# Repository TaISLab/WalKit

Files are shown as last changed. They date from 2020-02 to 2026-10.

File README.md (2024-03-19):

# WalKit


<p align="center">
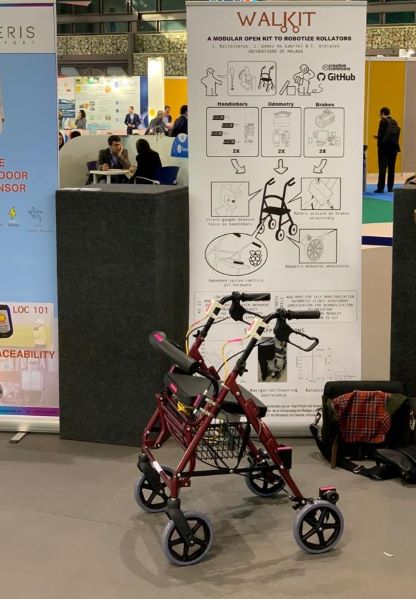
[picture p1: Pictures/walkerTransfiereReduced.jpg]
  
</p>

WalKit is an open hardware project created to monitor the elderly. It is modular, so different parameters, such as weight-bearing, cadence, activity duration, walking speed or other spatiotemporal gait parameters can be monitoring. 

- Packages in WalKit repository:
    - firmware: arduino codes for handles and wheels. 
    - hardware: 3d models and schematics.
    - walker_arduino: ros2 nodes to interact with USB arduino boards.   
    - walker_bringup: robot specific configuration scripts and tools. 
    - walker_centroid_support: obtains weight centroid based on current support.
    - walker_description: robot description.  
    - walker_diff_odom: odometry node.
    - walker_loads: reports partial supports on each leg.
    - walker_msgs: custom handle and wheel encoder msgs.
    - walker_navigation2: nav2 configuration for walker (TODO). 
    - walker_plot: Publishes Arrow marker based on handle force readings.  
    - walker_py_cluster: (TODO)
    - walker_simulation: roller simulation in gazebo.
    - walker_slam: (TODO)
    - walker_step_detector: reports step position.
    - walker_web_gui: web interface for tests.
            
- Repositories forked for this project
    - aws-robomaker-hospital-world: simulated hospital for gazebo.  
    - bwt901cl_pkg: IMU package.   
    - csm: ROS2 port of Andrea Censeis Scan matcher, needed by laser scan matcher package.
    - leap_motion: stereo camera package (DOES NOT WORK WITH arm64)  
    - ros2_laser_scan_matcher: provides odometry from laser readings.
    - rplidar_ros: RPLidar A1 package. 

<p align="right">(<a href="#top">back to top</a>)</p>

<!-- USAGE EXAMPLES -->
## Usage
The system can be launched with the following:
```
cd ~/walker_ws/src/WalKit/walker_bringup/config/
tmule -c walker.yaml launch --tag core
```
If you want to automatically start recording a rosbag as well, remove 'tag' option. They will be stored at '~/bagFolder'.

ROS launch files can be monitored at the tmux session. You can attach to it with the following command:
```
tmux a -t walker_ros2
```

You may have noticed we use Marc-Hanheide's [TMuLE](https://github.com/marc-hanheide/TMuLE) program to configure and manage a [tmux](https://github.com/tmux/tmux) session running all the components. TMuLE can be installed with:
```
sudo -H pip3 install tmule
```

<p align="right">(<a href="#top">back to top</a>)</p>

<!-- CONTRIBUTING -->
## Contributing

If you have a suggestion that would make this better, please fork the repo and create a pull request. You can also simply open an issue with the tag "enhancement".
Don't forget to give the project a star! Thanks again!

1. Fork the Project
2. Create your Feature Branch (`git checkout -b feature/AmazingFeature`)
3. Commit your Changes (`git commit -m 'Add some AmazingFeature'`)
4. Push to the Branch (`git push origin feature/AmazingFeature`)
5. Open a Pull Request

<p align="right">(<a href="#top">back to top</a>)</p>

<!-- LICENSE -->
## License

This project is licensed under the Creative Commons Attribution 4.0 - see [LICENSE](https://github.com/TaISLab/WalKit/blob/master/LICENSE) file for details.

<p align="right">(<a href="#top">back to top</a>)</p>

<!-- CONTACT -->
## Contact

Manuel Fernandez-Carmona - [@ermanazas](https://twitter.com/ermanazas) - manolofc at gmail.com

Project Link: [https://github.com/TaISLab/WalKit/tree/humble](https://github.com/TaISLab/WalKit/tree/humble)

<p align="right">(<a href="#top">back to top</a>)</p>

<!-- ACKNOWLEDGMENTS -->
## Acknowledgments

This work is funded by [Programa Proyectos RETOS del Ministerio de Ciencia, Innovación y Universidades (SAVIA: Sistema de Autonomía Variable para movIlidad Asistida, Ref: RTI2018-096701-B-C21)](http://www.grupoisis.uma.es/index.php?option=com_jresearch&view=project&task=show&id=208&Itemid=18&lang=es) at Málaga University, Spain

[Plan Propio de la Universidad de Málaga (E3-PROYECTOS DE PRUEBA DE CONCEPTO (E3/02/18))](https://www.uma.es/servicio-de-investigacion/cms/menu/plan-propio-de-investigacion/?set_language=en) at Málaga University, Spain

This great readme is based on [Othneil Drew](https://github.com/othneildrew/Best-README-Template)'s README template.

<p align="right">(<a href="#top">back to top</a>)</p>

<!-- MARKDOWN LINKS & IMAGES -->
<!-- https://www.markdownguide.org/basic-syntax/#reference-style-links -->
[contributors-shield]: https://img.shields.io/github/contributors/TaISLab/WalKit
[contributors-url]: https://github.com/TaISLab/WalKit/graphs/contributors
[forks-shield]: https://img.shields.io/github/forks/TaISLab/WalKit
[forks-url]: https://github.com/TaISLab/WalKit/network/members
[stars-shield]: https://img.shields.io/github/stars/TaISLab/WalKit
[stars-url]: https://github.com/TaISLab/WalKit/stargazers
[issues-shield]: https://img.shields.io/github/issues/TaISLab/WalKit
[issues-url]: https://github.com/TaISLab/WalKit/issues
[license-shield]: https://img.shields.io/github/license/TaISLab/WalKit
[license-url]: https://github.com/TaISLab/WalKit/blob/master/LICENSE
[product-screenshot]: images/screenshot.png

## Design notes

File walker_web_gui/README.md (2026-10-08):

# walker_web_gui

Web GUI to monitor the Walker and configure a test session, plus a console
tool to publish the same configuration. Static HTML/JS (no build step) that
talks to ROS 2 through rosbridge.

## Web GUI

rosbridge must be running:

    ros2 launch rosbridge_server rosbridge_websocket_launch.xml

Serve the page and open `http://<robot-ip>:4243/`:

    cd gui && python3 -m http.server 4243

Two tabs:
- **Monitor** (read-only): handle/leg loads, wheel encoders, IMU and a top-down
  view. Values with no recent data turn amber (stale) and then `—` (dead), so a
  frozen topic is not mistaken for a live one.
- **Sesión**: user data (id, gender, age, height, weight, Tinetti, condition)
  and handle height. **Actualizar configuración** publishes everything and is
  red while the form differs from what was last published.

Published topics: `/user_desc` (`walker_msgs/UserDesc`) and `/handle_height`
(`std_msgs/Int32`), both latched. Subscribed topics: loads, wheels, IMU, laser,
odom, and the two above.

The GUI does not start/stop the rosbag recording.

### rosbridge address

Defaults to `ws://<hostname used to open the page>:9090`. To override it, open
the page with `?ros=ws://<host>:9090` or use the gear icon next to the
connection status. The choice is remembered per browser (`localStorage`).
The connection is retried automatically with backoff.

### Layout

- `gui/index.html`: page structure.
- `gui/css/style.css`: styling.
- `gui/js/ros-link.js`: rosbridge connection with auto-reconnect, and the
  stale/dead tracking of displayed values.
- `gui/js/plot.js`: top-down Plotly view.
- `gui/js/app.js`: wires topics to the DOM and handles the configuration form.

## Console tool

Publishes the same `/user_desc` and `/handle_height` (transient_local) without
the GUI:

    ros2 run walker_web_gui console_config.py user_id:="manusete" gender:="Masculino" \
        age:="46" height:="175" weight:="104" tinetti_score:="28" \
        description:="Test ida y vuelta" handle_height:="4"

- Omitted fields take the GUI defaults (`UCAmI`, `Masculino`, 42, 175, 92, 24,
  `No previous condition`, handle height 4).
- `gender` is `Masculino` or `Femenino`, `tinetti_score` is 0-28, `handle_height`
  is 0-4.
- The node keeps running so late subscribers still get the latched values;
  Ctrl+C to exit. Add `once:="true"` to publish and exit instead.

Publishing from the console does not update the GUI form fields, and pressing
**Actualizar configuración** in the GUI overwrites what the console published.

## Licenses

Package: Creative Commons (see the repository `LICENSE`).

Bundled third-party libraries in `gui/`:
- roslibjs (`static.robotwebtools.org/`): BSD.
- plotly.js v1.58.5 (`cdn.plot.ly/`): MIT.

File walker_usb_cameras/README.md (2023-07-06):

# USB CAMERA CONFIGURATION PACKAGE

The aim of this package is to contain all calibration and configuration files needed to use an usb camera into walker system. 
This file is mostly a summary from info taken at:

[usb cam github](https://github.com/ros-drivers/usb_cam/tree/ros2)

[navigation tutorials: calibrating the camera](https://navigation.ros.org/tutorials/docs/camera_calibration.html)

[stereo calibration](http://wiki.ros.org/camera_calibration/Tutorials/StereoCalibration)

[ros2 stereo calibration](https://jeffzzq.medium.com/ros2-image-pipeline-tutorial-3b18903e7329)
## Check USB Camera
First step is check that camera works on our system.

### First terminal. 
Launch camera node without configuration:
```console
ros2 run usb_cam usb_cam_node_exe --ros-args -r __ns:=/camera
```

That command will show all possible formats, resolutions and fps and will start publishing data on ROS2.
```console
[INFO] [1688469843.164735462] [usb_cam]: Starting 'default_cam' (/dev/video0) at 640x480 via mmap (yuyv) at 30 FPS
[INFO] [1688469843.340893099] [usb_cam]: This devices supproted formats:
[INFO] [1688469843.340996505] [usb_cam]: 	YUYV 4:2:2: 640 x 480 (30 Hz)
[...]
[INFO] [1688469843.341301354] [usb_cam]: 	YUYV 4:2:2: 800 x 600 (20 Hz)
[...]
[INFO] [1688469843.341391412] [usb_cam]: 	YUYV 4:2:2: 1280 x 960 (5 Hz)
[...]
[INFO] [1688469843.341704075] [usb_cam]: 	Motion-JPEG: 800 x 600 (30 Hz)
[...]
[INFO] [1688469843.341899575] [usb_cam]: 	Motion-JPEG: 1280 x 960 (30 Hz)
[...]
[INFO] [1688469843.341927310] [usb_cam]: Setting 'brightness' to 50
[INFO] [1688469843.369696697] [usb_cam]: Setting 'white_balance_temperature_auto' to 1
[INFO] [1688469843.369725452] [usb_cam]: Setting 'exposure_auto' to 3
[INFO] [1688469843.378898988] [usb_cam]: Setting 'focus_auto' to 0
unknown control 'focus_auto'

[INFO] [1688469843.393069446] [usb_cam]: Timer triggering every 33 ms

```

Take note of the available formats, sizes and fps, as we will need them later on our "Params.yaml" file. 
Do not stop this command and open a second terminal.

### Second terminal. 
Here we will check that images are properly transmitted into ROS. First, lets check there are images:
```console
ros2 topic hz /camera/image_raw
```

We will see that FPS are similar to what was available.
```console
average rate: 29.813
	min: 0.032s max: 0.036s std dev: 0.00194s window: 31
average rate: 29.788
	min: 0.032s max: 0.036s std dev: 0.00195s window: 61
average rate: 29.819
	min: 0.032s max: 0.036s std dev: 0.00194s window: 91
```

Second command, see if the topic actually contains images:
```console
ros2 topic bw /camera/image_raw
```

We should see a decent amount of MB/s going around:
```console
Subscribed to [/camera/image_raw]
18.92 MB/s from 29 messages
	Message size mean: 0.61 MB min: 0.61 MB max: 0.61 MB
18.35 MB/s from 58 messages
	Message size mean: 0.61 MB min: 0.61 MB max: 0.61 MB
18.38 MB/s from 88 messages
	Message size mean: 0.61 MB min: 0.61 MB max: 0.61 MB
```

Finally, check that the topic can be seen in a ros2 app:
```console
ros2 run rqt_image_view rqt_image_view
```

Camera seems to work. Now we are ready to build both configuration and calibration files.

## configuration file (params.yaml)

This is the configuration file used by ROS2. It defines the camera configuration used. For example for our camera at video0 a params.yaml file:

````json
/**:
    ros__parameters:
      video_device: "/dev/video0"                                                   # <----------------- EDIT THIS TO MACH YOUR SYSTEM
      framerate: 20.0                                                               # <----------------- Taken from usb_cam_node_exe command
      io_method: "mmap"
      frame_id: "camera"                                                            # <----------------- careful with multiple cam systems
      pixel_format: "yuyv"                                                          # see usb_cam package, supported_formats for list of supported formats
      image_width: 800                                                              # <----------------- Taken from usb_cam_node_exe command
      image_height: 600                                                             # <----------------- Taken from usb_cam_node_exe command
      camera_info_url: "package://walker_usb_cameras/config/jpc_camera_info.yaml"   # <----------------- Calibration file. See next section
      camera_name: "jp_camera"                                                      # <----------------- This name must match whatever you put in the info_url file
      brightness: -1
      contrast: -1
      saturation: -1
      sharpness: -1
      gain: -1
      auto_white_balance: true
      white_balance: 4000
      autoexposure: true
      exposure: 100
      autofocus: false
      focus: -1
````

camera_info_url file will be created by callibration in next section.

## calibration file (camera_info.yaml) 

First we need a checkerboard for calibration. You can check [calib.io website](https://calib.io/pages/camera-calibration-pattern-generator) to generate any pattern. Specifically, we are using a “8x10” checkboard with 20mm squares. 

Actually we use a 7x9 checkerboard with 20mm squares, but calibration uses the interior vertex points, so a “8x10” board uses the interior vertex parameter “7x9”.

In a well-lit area, clear of obstructions and other check board patterns, point the checkboard to the camera and launch the camera calibration node:

```console
ros2 run camera_calibration cameracalibrator --size 7x9 --square 0.02 --ros-args -r image:=/camera/image_raw -p camera:=/my_camera
```

Now move, tilt and rotate the checkboard around until the calibrate button is highlighted. 

Click it to see the results. It takes around the minute for calibration to take place.

After the calibration is completed the save and commit buttons light up. And you can also see the result in terminal.

Press the save button to see the result. Data is saved to “/tmp/calibrationdata.tar.gz”

Inside the tar file, “ost.yaml” file is our camera_info.yaml, save from the "camera_name" field that needs to match the value in "params.yaml" file.

## launcher file
Last step is to create a launch file that uses our params.yaml to configure our camera. There is one at launch folder that can be used as template, just by changing the params.yaml file.

## STEREO USB Cameras

Create configuration file individually for each camera and create a launcher file with two 'usb_cam_node_exe' nodes, one per camera (see est_camera.launch.py as example).

Now proceed with calibration, but tell calibrator to use two cameras, i.e.
```console
ros2 run camera_calibration cameracalibrator --size 7x9 --square 0.02 --no-service-check  --approximate=0.3  --ros-args -p camera:=/est_camera  --remap /left:=/camera/left/image_raw   --remap /right:=/camera/right/image_raw

```

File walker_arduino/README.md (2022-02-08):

checking that the driver is running 
'''
screen /dev/right_wheel 115200
'''

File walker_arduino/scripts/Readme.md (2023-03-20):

# Check info from device connected as 'ttyUSB4'
```bash
udevadm info --attribute-walk --path=/sys/bus/usb-serial/devices/ttyUSB4
```
# Try rules written at '/etc/udev/rules.d' folder
```bash
udevadm control --reload-rules && udevadm trigger
```

# Virtual terminal to see output from new device
```bash
screen /dev/left_handle 115200
```
# Solve problem arduinos not appearing as ttyUSBx
Remove brtty

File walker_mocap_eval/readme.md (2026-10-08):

# walker_mocap_eval

Herramientas offline para recalcular, a partir de los rosbags etiquetados
con mocap (`soma13kp`/`datasets/labeled_bags`), los mismos parametros que
publican los nodos de `walker_loads` en marcha real -- y, en el futuro,
cualquier otro estudio que cruce mocap con datos del andador (postura,
centroide, estabilidad...).

No es un paquete ROS: como `walker_step_detector/scripts/*.py`, son
scripts de analisis que se ejecutan directamente con
`python3 scripts/xxx.py` tras sourcear `/opt/ros/jazzy/setup.bash` (hace
falta `rosbag2_py`/`rclpy` para deserializar los bags), y no forman parte
del build de colcon.

## Por que un paquete nuevo (y no meterlo en walker_loads o walker_step_detector)

- `walker_loads` es el paquete del nodo ROS en produccion
  (`gait_monitor_speed`, `partial_loads`); no es el sitio para tooling de
  analisis offline.
- `walker_step_detector/scripts/mocap_bag_io.py` ya hace algo parecido,
  pero esta acoplado a las necesidades del detector de pasos (frame
  "laser", solo tobillos/rodillas). Los estudios del plan (paso 3: postura,
  centroide, angulos de codo...) necesitan el resto de keypoints
  etiquetados (hombros, caderas, muñecas...), asi que se generalizo aqui en
  vez de forzar ese acoplamiento.

La calibracion mocap->base_footprint (`mocap_to_base_footprint.yaml`) SI se
reutiliza tal cual desde `walker_step_detector/config/` (fuente unica),
solo se referencia por ruta relativa por defecto.

## Estructura

```
mocap_eval/            <- libreria importable (sin dependencia de ROS salvo bag_io.py)
  bag_io.py             lectura de bags etiquetados, marcadores/rigid_bodies, proyeccion mocap->frame andador
  contact_events.py     eventos/intervalos de apoyo por pie a partir de cinematica del tobillo (mocap no mide carga)
  gait_metrics.py       puerto puro-Python de walker_loads/gait_monitor_speed.py (GaitMonitorSp)
  posture_metrics.py    inclinacion de tronco, ancho de paso, doble apoyo, margen de estabilidad lateral (punto 3)
  cog_estimation.py     centro de gravedad por modelo segmentario (De Leva 1996) + sexo/peso del usuario (punto 3)
  extra_metrics.py      codo, muñeca, reparto de peso en manetas, yaw/curvatura, oscilacion vertical del CoM, indice de
                        inestabilidad, Symmetry Index (puntos 3-elbow/4/5/8/9/11 del plan + punto 2 de la ampliacion)
  imu_metrics.py        RMS, Harmonic Ratio, regularidad por autocorrelacion, y aceleracion AP/ML del andador por mocap
                        (punto 1 de la ampliacion)
  correlation_utils.py  correlacion de Pearson por sujeto (CA/LA/MF/MT) + TOTAL (puntos 2 y 5 de la ampliacion)

scripts/   (orden de ejecucion y ejemplos de comandos: ver scripts/README.md)
  compute_gait_from_mocap.py       CLI: bag(s) etiquetado(s) -> Step/Stride time/length, NoS, d, CAD, WV (punto 1 del plan)
  selftest_gait_metrics.py         auto-test con datos sinteticos (sin bags), valida el puerto del algoritmo
  mocap_odom_bridge.py             nodo ROS: republica rigid_bodies[0] (mocap) como /odom (ver punto 2 mas abajo)
  compare_gait_mocap_vs_walker.py  punto 2: lanza el pipeline real (replay_offline.launch.py) contra cada bag,
                                    graba lo que publica gait_monitor_speed y lo compara con compute_gait_from_mocap.py
  compute_posture_from_mocap.py    CLI: bag(s) etiquetado(s) -> parametros posturales/estabilidad (punto 3)
  selftest_posture_metrics.py      auto-test con datos sinteticos (sin bags), valida la geometria de posture_metrics.py
  compute_cog_from_mocap.py        CLI: bag(s) etiquetado(s) -> centro de gravedad (modelo De Leva + sexo/peso, punto 3)
  selftest_cog_estimation.py       auto-test con datos sinteticos (sin bags), valida el modelo segmentario
  compare_cog_mocap_vs_walker.py   punto 3 (comparacion): CoM de mocap vs /support_centroid real (walker_centroid_support)
  eval_odom_against_mocap.py       evalua una odometria grabada (/odom del EKF laser+IMU, walker_bringup) contra el mocap:
                                    ATE tras alinear con Umeyama 2D + deriva en % del recorrido (antes en walker_step_detector/scripts)
```

## Uso

```bash
source /opt/ros/jazzy/setup.bash
cd WalKit/walker_mocap_eval

# validar la logica portada (no requiere bags ni $DATASETS)
python3 scripts/selftest_gait_metrics.py

# un bag
python3 scripts/compute_gait_from_mocap.py --bag $DATASETS/labeled_bags/CA_test01

# todos los bags etiquetados
python3 scripts/compute_gait_from_mocap.py --bags-dir $DATASETS/labeled_bags \
    --out /tmp/mocap_gait_results.json
```

## Recorte a la ventana `/tag` (punto 1 y 2, por defecto)

Cada bag de `datasets/labeled_bags` trae exactamente 2 mensajes en el topic
`/tag` (`builtin_interfaces/msg/Time`) -- los mismos marcadores de
inicio/fin de test (pulsacion de boton) que usa `mocap_analysis/scripts/
merge_rosbags.py` para sincronizar y recortar bags al fusionarlos. Fuera de
esa ventana suele haber tiempo de calibracion/colocacion del usuario, no
marcha real: en `CA_test01`, por ejemplo, la ventana `/tag` dura 52.9 s de
los 89.3 s totales del bag.

Por defecto (`compute_gait_from_mocap.py` y `compare_gait_mocap_vs_walker.py`,
`--ignore-tags` para desactivarlo en ambos):
  - **Lado mocap**: `/labeled_markers` y `/rigid_bodies` se recortan a
    `bag_io.read_tag_window()` antes de detectar eventos de apoyo.
  - **Lado andador** (punto 2): `replay_offline.launch.py` arranca el
    replay en el primer `/tag` (nuevo argumento `start_offset`, segundos de
    bag desde su propio inicio, `ros2 bag play --start-offset`) y
    `compare_gait_mocap_vs_walker.py` solo espera lo que dura la ventana
    entre los dos `/tag` (en vez de la duracion completa del bag), para que
    ambos lados vean la misma porcion "activa" del test.

Impacto en `CA_test01` (mocap-only, bag completo -> ventana `/tag`): cadencia
59.2 -> 85.0 pasos/min, velocidad 0.329 -> 0.542 m/s, NoS 87 -> 75 (menos
pasos porque la ventana es mas corta, pero mas *densos* -- el tiempo muerto
fuera de la ventana no aportaba pasos reales, solo alargaba `Tr` y diluia
la cadencia). Es una correccion sistematica: todo el reparto de tiempo real
de marcha estaba subestimando la velocidad/cadencia real del usuario al
promediar sobre tiempo que no era marcha.

## Diseño: como se recalcula cada parametro

| Parametro (GaitStamped/WalkStats) | Como se obtiene aqui | Fuente en el andador real |
|---|---|---|
| Step/Stride time y length por pierna | `gait_metrics.py`, puerto **literal** de `GaitMonitorSp.update_stats()`/`timer_callback()`: mismas formulas, mismo criterio de arranque (>2 eventos por pierna), mismas medias acumuladas (`nanmean` desde el inicio) | `walker_loads/gait_monitor_speed.py` |
| Evento de "apoyo" por pierna | `contact_events.detect_stance_events()`: minimo de velocidad horizontal del marcador de tobillo (`l_ankle`/`r_ankle`) por episodio bajo un umbral (0.25 m/s por defecto) | `StepStamped.load` pasando a >0 (celula de carga) |
| Posicion del evento | Se proyecta desde el frame "map" del mocap al frame del andador ("laser") con `rigid_bodies[0].pose` + la calibracion ICP existente + el offset fijo laser<-base_footprint (igual que `walker_step_detector/scripts/mocap_bag_io.py`) | `StepStamped.position`, ya en frame "laser"/"base_footprint" (deteccion laser) |
| Distancia recorrida (`d`) | Arclength del propio `rigid_bodies[0]` (andador) en el mocap, acumulada entre el primer y el ultimo evento de paso | **Ver discrepancia abajo** |
| `avg_step_speed_{left,right,all}` | Media de (longitud de paso / tiempo de paso), no publicada por el nodo real pero si mencionada en el docstring/spec original de `GaitMonitorSp` | No publicada actualmente por ningun topic |

**Resultados sobre los 47 bags, solo mocap, con recorte `/tag`**
(`/tmp/mocap_gait_tagged_full.json`): sin fallos en ningun bag. Cadencia
media 100.4 pasos/min (std 29.4), velocidad media 0.403 m/s (std 0.119) --
sensiblemente mas altas y mas representativas de la marcha real que las
que salian promediando sobre el bag completo (esas incluian el tiempo de
calibracion/colocacion, ver seccion anterior). `SpL`/`SdL` medios
0.14-0.31 m segun pierna/campo, consistentes entre bags del mismo sujeto.

## Bug corregido en el nodo real (encontrado antes del punto 2)

`walker_loads/gait_monitor_speed.py::GaitMonitorSp.getTravelledDist()`
**no usaba la distancia real acumulada**: `self.travelled` se calculaba
correctamente en `odom_callback()` (suma de desplazamientos consecutivos de
`/odom`), pero `timer_callback()` llamaba a `getTravelledDist()`, que
ignoraba `self.travelled` y devolvia una formula con una constante de
prueba hardcodeada (`test_time = 14.48`, pista de `8.0` m, resultado capado
a 8m). Es decir, `d`, `CAD` y `WV` del nodo real no reflejaban la distancia
ni la velocidad reales del test. **Corregido**: `timer_callback()` ahora usa
`self.travelled` directamente; `getTravelledDist()` se elimino.

## Punto 2: pipeline real vs mocap, resultados sobre los 47 bags

`compare_gait_mocap_vs_walker.py` lanza `walker_loads/launch/
replay_offline.launch.py` (box_filter -> km_detect_steps -> partial_loads ->
mocap_odom_bridge -> gait_monitor_speed) contra cada uno de los 47 bags de
`datasets/labeled_bags`, graba el ULTIMO mensaje de `/left_gait_stats`,
`/right_gait_stats` y `/global_gait_stats` (GaitStamped/WalkStats son
acumulados desde el arranque del nodo, asi que el ultimo mensaje ya refleja
todo el historial) y lo compara campo a campo con `compute_gait_from_mocap.py`.

**`/odom` real no es viable en estos bags**: `/left_wheel`/`/right_wheel`
(walker_diff_odom) estan rotos -- comprobado en CA_test01, `/right_wheel`
no tiene ni un mensaje y `/left_wheel` esta congelado (3475->3476 ticks en
~90s). `mocap_odom_bridge.py` republica `rigid_bodies[0]` (mocap) como
`/odom` en su lugar -- valido porque `self.travelled` solo acumula deltas
de posicion consecutivos, invariante a que frame se use.

Resultados **tras el fix de timestamp** (43/47 bags con datos suficientes;
ver tambien el docstring de `replay_offline.launch.py` para el detalle del
bug):

| Campo | MAE | MAPE | Lectura |
|---|---|---|---|
| `d` (distancia) | 0.17 m (mediana 2.3 cm) | 1.1% | **Validado**: coincide con mocap |
| `wv` (velocidad) | 0.044 m/s (mediana 0.034) | 15.7% | Bueno, hereda la calidad de `d` |
| `cad`/`NoS`/`SpT`/`SdT` | ver abajo | ver abajo | **Bimodal**: 13 bags muy bien, 30 todavia mal -- no es un error uniforme |

**Causa raiz encontrada y corregida** (no era un bug de `gait_monitor_speed`):
se descarto primero la hipotesis de zona de deteccion fija en tests de
"movimiento en circulos" (la mayoria de los 47) -- los tests "ida y vuelta"
(LA_test\*, sin ese patron) mostraban el mismo subconteo severo, y
`fixed_frame_active_area_x`/`_y` (que este launcher pasaba a
`km_detect_steps`) resultaron ser parametros **muertos** (el .cpp nunca los
lee, ya quitados del launcher).

La causa real estaba en `walker_step_detector/src/km_detect_steps.cpp`:
con `kalman_enabled: true` (necesario aqui -- con `false`,
`StepStamped.tracked` nunca se pone a `true` y `partial_loads` no publica
nada en absoluto), `laserCallback()` sellaba cada `StepStamped` predicho con
`this->now()` (reloj de pared) en vez del timestamp del propio escaner. En
vivo eso no importa (reloj de pared ~= tiempo del sensor), pero reproduciendo
un bag a `--rate 4.0` (el valor por defecto de este launcher) el reloj de
pared avanza 4 veces mas rapido que la linea de tiempo real del bag -- y
`Tr`/`SpT`/`SdT` (calculados como diferencias de esos timestamps) salian
truncados a ~1/rate de su valor real. Confirmado reproduciendo a
`rate:=1.0` con el bug todavia presente (Tr paso de ~12% a ~73% de la
duracion real del bag, sin tocar nada mas) antes de tocar el C++.
**Corregido**: se sella con `rclcpp::Time(scan->header.stamp)` en su lugar
(recompilado con `colcon build --packages-select walker_step_detector`).
Tras el fix, a `rate=4.0`, `Tr` en CA_test01/02/03 paso de ~10s a ~50-60s
(de ~85-90s reales), y `CA_test03` (antes sin datos) ya produce resultados.

Tras el fix, sobre los 47 bags, el resultado es **bimodal**, no un error
uniforme:

- **13 bags funcionan bien** (`MF_test17-20`, `MT_test11-20` salvo
  `MT_test13`): NoS del walker entre 70% y 153% del de mocap, `Tr` cubre
  todo el bag, errores de SpT/SdT por debajo de ~2s.
- **30 bags siguen mal** (todos los `CA_test*` y `LA_test*` restantes, y
  `MF_test01-15`): NoS del walker solo 8-23% del de mocap, igual de mal que
  antes del fix.
- **4 bags sin datos**: `CA_test03`, `LA_test5`, `MF_test02`, `MF_test16`.

Se comprobo si la diferencia esta en la calidad del propio `/scan` (huecos,
timestamps duplicados o no monotonos) entre un bag "bueno" y uno "malo":
**no lo esta** -- `CA_test01` (malo) y `MF_test17` (bueno) tienen el mismo
comportamiento de timestamp en `/scan` (mediana de intervalo ~0.12-0.18s,
sin duplicados, sin retrocesos), y `MF_test16` (misma sesion y calidad de
escaneo que `MF_test17`) sigue sin producir ningun dato. Es decir, lo que
diferencia un bag bueno de uno malo pasa DESPUES del `/scan` -- dentro del
clustering/tracking de `km_detect_steps` o de la asignacion de carga de
`partial_loads` -- y no se ha perseguido mas en esta sesion: hay una tarea
marcada para `walker_step_detector` sobre esto (el usuario ya la inicio
como sesion aparte mientras esta investigacion seguia en marcha aqui --
revisar ambas antes de seguir, y usar esta lista de bags buenos/malos como
punto de partida).

### Segunda causa encontrada (walker_step_detector): `ms_period` mal nombrado

La tarea marcada arriba ("hay una tarea marcada para walker_step_detector...
revisar ambas antes de seguir") ya tiene respuesta: la diferencia entre los
13 bags "buenos" y los 30 "malos" no estaba en `km_detect_steps` ni en
`/scan`, sino en `partial_loads.launch.py`. Ese launcher pasaba
`{'period': 0.05}` al nodo `partial_loads`, pero `partial_loads.cpp` nunca
declara un parametro `period` -- solo `ms_period` (int, ms, default 500).
El valor de 0.05 (pensado como 50ms/20Hz) se ignoraba en silencio y el nodo
corria siempre a su default de 2Hz.

Por que eso explica justo el patron **bimodal**: `partial_loads` decide
"que pierna carga" en un `create_wall_timer` -- reloj de PARED, no afectado
por `--rate` del bag. A 500ms de periodo real y `rate=4.0`, cada muestra de
esa decision cae cada ~2s de tiempo de BAG. Un bag con zancada lenta (SpT
mayor que esos ~2s) todavia captura suficientes cruces load>0 para verse
razonable; un bag con zancada mas rapida que el intervalo de muestreo
alias-a por completo la señal -- exactamente los 30 bags "malos" (y los 4
sin ningun dato, caso extremo de lo mismo).

**Fix**: `partial_loads.launch.py` ahora pasa `{'ms_period': 50}` (nombre
correcto). Sin recompilar (es un parametro de lanzamiento, no C++).
Revalidado con `compare_gait_mocap_vs_walker.py` sobre los 47 bags
completos (`ROS_DOMAIN_ID` propio, ver `ROS_DOMAIN_ID_EVAL` en el script):

| Campo | Antes (tras fix de timestamp, arriba) | Despues (+ fix de `ms_period`) |
|---|---|---|
| Bags con datos suficientes | 43/47 (4 sin ningun `GaitStamped`) | **47/47** |
| `NoS` | bimodal (13 bien, 30 al 8-23% del real) | MAE=23.5 pasos, medianaAE=18, MAPE=25.1% (uniforme, sin bags a cero) |
| `d` | MAPE 1.1% | MAPE 1.3% (sin cambio, esperado) |
| `wv` | MAPE 15.7% | MAPE 13.2% |
| `cad` | — | MAE=22.5, MAPE=29.4% |
| `SpT`/`SdT`/`SpL`/`SdL` | heredaban el error bimodal de NoS | siguen con MAPE 30-230% -- heredan el ~25% de error de `NoS` que queda |

`NoS` pasa de infracontar severamente (o fallar del todo) a un error
uniforme del ~25%, sin bags catastroficos. Ese ~25% residual es,
presumiblemente, ruido de `km_detect_steps` (fuerza siempre exactamente 2
clusters por k-means sobre `/scan_feet`, sin filtro de confianza como el
Random Forest de `detect_steps` -- ver `getCentroids()`): con la señal ya
muestreada a un ritmo razonable, ese ruido dispara algun cruce `load>0` de
mas o de menos. Detalle y numeros del spot-check inicial (2 bags) en el
comentario de `partial_loads.launch.py`. No se ha perseguido mas aqui --
encaja con el trabajo ya activo en `walker_step_detector` sobre la calidad
de deteccion de `km_detect_steps` frente a `detect_steps` (RF).

**Reejecutado sobre los 47 bags completos** para este informe (mismo
`compare_gait_mocap_vs_walker.py`, `ROS_DOMAIN_ID` propio): **47/47 bags con
datos**, ningun fallo. `NoS` MAE=31.4 pasos, medianaAE=31, MAPE=34.6% --
algo peor que el 25.1% del spot-check anterior, esperable dado que el
muestreo de `partial_loads` sigue en reloj de pared (`create_wall_timer`,
no en tiempo de bag) y por tanto tiene algo de varianza de una corrida a
otra. `d` (MAPE 1.3%) y `wv` (MAPE 13.4%) se mantienen validados.

Encontrado en esta corrida: `CA_test09` tiene valores de `SpL`/`SdL` del
andador disparatados (`left_sdl`=87m, `right_spl`=39m, `right_sdl`=76m de
"longitud de zancada") que inflan artificialmente el MAPE agregado de esos
4 campos (200-2800%) muy por encima de lo que reflejan el resto de bags
(medianaAE de esos mismos campos: 0.15-0.21 m, mucho mas razonable -- usar
la mediana, no la media, al leer esa fila de la tabla).

**Causa real de `CA_test09` y estado final, tras coordinarse con el hilo
`walker_step_detector` (mejoras)**: mi hipotesis inicial (clustering sin
filtro de confianza en `km_detect_steps`) no era la causa -- esa sesion
diagnostico el verdadero origen: `TrackLeg::t` se inicializaba a 0 como
centinela de "nunca predicho", pero `predict_step()` lo usaba tal cual en
el primer `u.dt()=(ti-t)*1e-9`, dando un dt de ~1.79e9s (segundos desde el
epoch Unix) en vez de un intervalo real. Ese dt gigante dispara la
covarianza del EKF desde el primer ciclo (via el jacobiano de
`SystemModelLeg.hpp`), y la siguiente actualizacion salta a cientos de
metros -- afecta por igual a las tres variantes de detector (`km`, `rf`,
`seg`, mismo `TrackLeg` compartido); `rf`/`seg` no lo mostraban en
`CA_test09` por pura suerte de timing, no porque no les afecte. Fix (su
sesion, `track_leg.cpp::predict_step()`): si `t==0`, fijar `t=ti` antes de
calcular `dt` -- la primera prediccion usa `dt=0` en vez de "tiempo desde
el epoch".

De paso, esa sesion recomendo cambiar de `km_detect_steps` a `detect_steps`
(Random Forest) en `replay_offline.launch.py` -- validado por ellos en
95.7-95.9% de match_rate sobre estos mismos 47 bags (vs ~81% de `km`).
Aplicado, y de camino encontramos (yo) que `detect_steps.cpp` y
`detect_steps_s.cpp` tenian el MISMO bug de timestamp de reloj de pared que
ya habia corregido en `km_detect_steps.cpp` (`this->now()` en vez de
`scan->header.stamp`/`seg_array->header.stamp`) -- corregido en los tres.

**Resultado final, los tres fixes juntos (timestamp x3 variantes + `t==0`
del EKF + cambio a RF), sobre los 47 bags completos**:

| Campo | Solo timestamp+`ms_period` (arriba) | + `t==0` fix + RF (final) |
|---|---|---|
| Bags con datos | 47/47 | 47/47 |
| `NoS` | MAE=31.4, MAPE=34.6% | **MAE=24.6, medianaAE=20, MAPE=24.0%** |
| `d` | MAPE 1.3% | MAPE 1.3% (sin cambio, esperado) |
| `wv` | MAPE 13.4% | MAPE 15.4% |
| `cad` | MAPE 40.1% | MAPE 27.7% |
| `SpT`/`SdT` | MAPE 28-137% | MAPE 26-58% |
| `SpL`/`SdL` | MAPE 200-2800% (outlier `CA_test09`) | **MAPE 52-98%, sin outliers** |

`CA_test09` ya no tiene valores disparatados (antes 87/39/76 m de "longitud
de zancada", ahora 0.07-0.13 m como el resto de bags). El error residual de
`SpL`/`SdL`/`SpT`/`SdT` (25-100% MAPE) es ahora ruido "normal" de deteccion,
no un unico frame corrupto contaminando toda la media -- consistente con
que `gait_monitor_speed.py` sigue promediando con `nanmean` simple sin
rechazar outliers puntuales (no corregido, y ya no hace tanta falta con el
EKF corregido, pero sigue siendo una fragilidad de diseño a tener en cuenta
si aparece otro bug de esta familia).

### Rehecho con recorte a la ventana `/tag` (puntos 1 y 2)

Con el recorte a `/tag` activado por defecto (ver seccion arriba) en ambos
lados de la comparacion, sobre los 47 bags completos:

| Campo | Bag completo (estado anterior) | Ventana `/tag` (final) |
|---|---|---|
| `NoS` | MAE=24.6, MAPE=24.0% | MAE=22.9, medianaAE=16, MAPE=25.6% (similar) |
| `d` | MAPE 1.3% | MAPE 3.5% (peor, ver nota abajo) |
| `wv` | MAPE 15.4% | **MAPE 5.9%** (mejor) |
| `cad` | MAPE 27.7% | **MAPE 23.4%** (mejor) |
| `SpT`/`SdT` | MAPE 26-58% | MAPE 24-76% (similar, `right_spt` peor en algun bag puntual) |
| `SpL`/`SdL` | MAPE 52-98% | MAPE 49-87% (similar) |

`wv`/`cad` mejoran claramente (igual que ya se vio en mocap-only: promediar
sobre la ventana activa da una cadencia/velocidad mas representativa que
diluirla con tiempo de calibracion). `d` empeora un poco -- hipotesis mas
probable: con una ventana mas corta, el tiempo de arranque del pipeline real
(`partial_loads` necesita ver las 4 fuentes frescas antes de publicar nada,
`first_data_ready_`) es una fraccion mayor del total, así que se pierde
proporcionalmente mas distancia real al principio de la ventana que con el
bag completo. No investigado mas a fondo. El resto de campos se mantiene en
el mismo orden de magnitud que sin recortar -- el recorte a `/tag` no
"arregla" nada adicional sobre el punto 2 en si (esa mejora ya vino de los
fixes del hilo walker_step_detector), pero da una medida mas representativa
de la marcha real del usuario en ambos metodos, que es lo que se pidio.

## Punto 3: parametros posturales/de estabilidad desde mocap

`posture_metrics.py` (+ CLI `compute_posture_from_mocap.py`) implementa los
4 candidatos "baratos" de la tabla del plan (los que no requieren datos del
andador para calcularse, solo mocap) sobre la misma base que el punto 1
(`bag_io.py`, `contact_events.py`):

| Parametro | Como se calcula | Candidato a correlar con (andador) |
|---|---|---|
| Inclinacion de tronco (total, sagital, frontal) | Angulo entre el vector cadera_media->hombro_medio y la vertical, en cada frame donde esten los 4 marcadores (`l/r_shoulder`, `l/r_hip`) | Reparto de carga manetas/pies (`partial_loads`), centroide de soporte (`walker_centroid_support`) |
| Ancho de paso | Distancia lateral (proyectada al eje del andador via `rigid_bodies[0]` yaw) entre cada evento de apoyo y el del pie contrario mas cercano en tiempo -- reutiliza `contact_events.detect_stance_events()` del punto 1 | No publicado hoy; derivable de las mismas posiciones que ya usa el detector de pasos |
| Tiempo de doble apoyo (%) | Solape entre `contact_events.detect_stance_intervals()` de ambos pies, sobre el total | `is_left_load`/`is_right_load` de `gait_monitor_speed.py` ya existen internamente, no se publican |
| Margen de estabilidad lateral | Punto medio de caderas (proxy de CoM) proyectado sobre el eje lateral del andador, normalizado entre los DOS TOBILLOS reales (0=borde, 1=centro) -- misma formula que `walker_stability.py::y_sta`, pero con BoS real en vez de estimado por tablas antropometricas | **Validacion directa** de `StabilityStamped.sta` |

`indexed_nearest()` en `bag_io.py`: la primera version de `trunk_lean_series()`
usaba `nearest()` (escaneo lineal) contra 3 tracks por cada muestra de otro
(miles a ~120Hz) -- O(n^2), minutos por bag. Sustituido por una version
indexada con `bisect` (una vez por track, O(log n) por consulta): segundos
por bag. Cualquier funcion futura que consulte un track repetidamente
deberia usar `indexed_nearest()`, no `nearest()`.

Resultados con recorte `/tag` (por defecto ahora, `--ignore-tags` para el
bag completo): `/tmp/mocap_posture_tagged_full.json`, sin fallos en los 47
bags. El recorte cambia mucho una metrica en concreto: **doble apoyo**, que
con el bag completo salia 6-67% (dominado por el tiempo de pie quieto antes
y despues del test, que es doble apoyo permanente pero no marcha), baja a
un rango mucho mas realista de **3-56%** una vez restringido a la ventana
activa -- p.ej. `CA_test01` 44.8% -> 11.6%, `CA_test02` 56.8% -> 9.9%. El
resto de parametros cambia menos: inclinacion de tronco 3.9-35.7 (similar
rango, algo mas alta en general al quitar los tramos de pie quieto/recto),
ancho de paso 0.08-0.42 m, margen lateral 0.26-0.85.

**Correlacion "maneta baja -> mas inclinacion" mas clara con el recorte**:
CA (postura inclinada, `handle_height=0`, test07/08) 24.2 grados de media
vs 11.7 en el resto de tests del mismo sujeto (antes del recorte: 15.2 vs
11.3 -- la separacion se hace mucho mas nitida al quitar el ruido de los
tramos sin marcha real); MT (test19/20) 14.6 vs 9.8 (antes 13.4 vs 9.0).
Es exactamente el tipo de correlacion mocap<->parametro-del-andador (aqui,
`handle_height`) que busca el punto 3 del plan, y ahora con menos
solapamiento que antes de recortar a `/tag`.

Cruzar el resto de estos parametros con datos PUBLICADOS por el andador
(inclinacion de tronco vs asimetria real de `/left_handle`-`/right_handle`,
o el margen de estabilidad de aqui contra `StabilityStamped.sta`) es el
paso siguiente logico -- requiere decidir que bags tienen datos de
manetas/centroide utilizables (ver limitaciones del punto 2 arriba: la
extraccion en vivo depende del mismo pipeline con el problema de
`km_detect_steps` ya descrito) y no se ha hecho todavia.

## Punto 3: centro de gravedad (De Leva) vs `support_centroid` del andador

`cog_estimation.py` estima el CoM de cuerpo completo por frame combinando
la postura del mocap con el sexo y el peso del usuario (de
`test_config.txt`), usando el modelo antropometrico segmentario de
**De Leva (1996)** ("Adjustments to Zatsiorsky-Seluyanov's segment inertia
parameters", J Biomech 29(9):1223-30 -- tabla verificada contra el paper
original, no de memoria): cada segmento (tronco, brazo, antebrazo, muslo,
pantorrilla) se calcula interpolando entre sus dos articulaciones segun la
fraccion de posicion de De Leva; los 3 segmentos sin marcador propio en el
esquema de 13 keypoints (cabeza, manos, pies -- sin vertice/dedos/punta de
pie) se aproximan con su masa concentrada en la articulacion proximal
disponible (hombro, muñeca, tobillo). Esos 3 segmentos suman ~8.5% de la
masa corporal, y el sesgo que introduce esa aproximacion es casi todo
vertical (con el tronco razonablemente recto, cabeza/manos/pies caen casi
encima de su articulacion proximal en el plano horizontal) -- para
comparar la posicion horizontal contra `support_centroid` (el uso
previsto), el efecto es minimo. La ALTURA del usuario no se usa para
derivar la posicion (los segmentos ya tienen longitud real, medida por el
mocap en cada frame) -- solo como contraste (`com_height_frac_of_stature`).

**Resultados mocap-only sobre los 47 bags, con recorte `/tag`**
(`compute_cog_from_mocap.py`, `/tmp/mocap_cog_tagged_full.json`): sin
fallos en ningun bag. Fraccion CoM/estatura entre 0.552 y 0.608 (media
~0.59) -- practicamente identica al calculo sobre el bag completo (0.552-
0.613): a diferencia del doble apoyo (arriba), la altura del CoM no se ve
afectada por el tiempo de pie quieto (la postura en reposo es similar en
altura a la postura de marcha). Consistente con el valor tipico de
literatura para un adulto de pie (~0.55) -- algo mas alto, razonable dado
que el usuario sujeta las manetas del andador con los brazos levantados en
vez de colgando a los lados. Patron por sujeto: MT (67 kg) sistematicamente
mas bajo (0.552-0.578) que CA/LA/MF (0.571-0.608) -- para interpretar esto
como algo mas que variacion individual de proporciones corporales hace
falta cruzarlo con la altura real de manetas usada en cada test
(`handle_height` de `test_config.txt`), no hecho todavia.

**Comparacion contra el andador**: `compare_cog_mocap_vs_walker.py` anade
`walker_centroid_support` (topics por defecto, sin remapear: ya coinciden
con lo que publica `partial_loads`) a `replay_offline.launch.py`, graba
`/support_centroid` durante el replay real, y lo compara (media sobre toda
la grabacion, en frame "laser", proyectando el CoM de mocap con la misma
calibracion ICP que el punto 1/2 -- comparar medias en vez de instante a
instante porque `support_centroid` hereda el ruido de deteccion de piernas
que le queda a `km_detect_steps`).

**Resultado sobre los 47 bags: error medio ~15 cm entre el CoM de mocap
(De Leva) y el centroide de carga real del andador** -- mediana 0.155 m,
media 0.145 m excluyendo el bag con outlier (ver abajo), rango 3.6-29 cm en
el resto. Es una correlacion solida para una primera comparacion: dos
metodos completamente independientes (postura+antropometria vs celdas de
carga) situan el punto de equilibrio del usuario en el mismo sitio con
~15 cm de margen, sobre un andador cuya base mide del orden de 1 m.

`x` de ambos metodos es consistentemente negativo (-0.4 a -0.85 m mocap,
-0.5 a -0.79 m andador) y del mismo orden en todos los bags -- el usuario
carga tipicamente por detras del origen del frame "laser" en ambos metodos,
como cabria esperar. `y` de ambos ronda 0 en la mayoria de bags (usuario
centrado lateralmente), con las mismas excepciones logicas (MF_test17/18,
CA_test06: asimetria real, mayor en el metodo de mocap que en el del
andador -- consistente con que `support_centroid` reparte peso segun carga
MEDIDA en los 4 puntos de contacto, mientras que el CoM de mocap refleja la
postura completa, que puede desviarse mas).

**`CA_test09` sale como outlier severo** (`walker_y`=35.7 m, `dist_err_m`
=35.8 m): la MISMA deteccion espuria de `km_detect_steps` que ya contamino
`SpL`/`SdL` de `gait_monitor_speed` en este bag (punto 2 arriba) contamina
tambien `support_centroid` -- confirma que es un problema sistemico de
"sin filtro de confianza + promediado no robusto" que afecta a CUALQUIER
nodo que promedie sobre toda la sesion (`gait_monitor_speed` Y
`centroid_support`, ambos), no algo especifico de uno de los dos.

### Rehecho con el fix del EKF (`t==0`) + recorte a `/tag`

Repetido tras los fixes del punto 2 (RF + `t==0` del EKF) y con el recorte
a la ventana `/tag` activado por defecto en ambos lados: **error medio
0.107 m, mediana 0.106 m, maximo 0.199 m -- sin ningun outlier en los 47
bags** (antes: mediana 0.155 m con `CA_test09` disparado a 35.8 m). Mejora
en las tres cosas a la vez: el fix del EKF quita el outlier de raiz (igual
que en el punto 2), y el recorte a `/tag` quita el tiempo de pie quieto
(que desplaza el centroide real hacia una postura de reposo distinta de la
postura de marcha que describe el CoM de mocap). El patron de `x`/`y` por
sujeto/bag se mantiene igual que antes (ver parrafo anterior).

## Informe completo y flujo de ejecucion

`scripts/README.md` documenta el orden de ejecucion de todos los scripts
(metricas mocap -> `export_bag_timeseries.py` -> `derive_comparison_metrics.py`
-> `build_master_report_data.py` -> `generate_latex_report.py`). El informe
LaTeX resultante (11 puntos + ampliacion, tablas por bag con agregados POR
SUJETO CA/LA/MF/MT mas una fila TOTAL, formulas, bibliografia) se genera
con `generate_latex_report.py`; no se versiona el .tex/.pdf, se regenera.

Convencion de agregacion: cada bag es una repeticion de test de uno de 4
sujetos (prefijo `CA`/`LA`/`MF`/`MT`; 10/7/20/10 bags). Los agregados se
dan por sujeto, no mezclando los 47 bags, porque difieren en sexo, peso y
altura.

**Repetibilidad del replay (limitación abierta).** La reproducción del lado
andador no es determinista: a rate 4, `partial_loads` decide qué pierna
carga con un temporizador de reloj de pared, y el resultado depende de
dónde cae cada decisión en el bag (y de la carga de CPU). Dos ejecuciones
dieron MAPE del SpT izquierdo de 38% (30 sep-1 oct 2026) y 58% (6 oct 2026).
Todas las cifras del lado andador del informe son de **una sola ejecución,
la de octubre de 2026**, y las cifras escritas a mano en el texto de
`generate_latex_report.py` (literatura, limitaciones, conclusiones) hay que
revisarlas si se repite el replay; las tablas sí se recalculan. No está
cuantificada la variabilidad entre repeticiones. Lo calculado solo desde
mocap o sensores grabados (marcha mocap, postura, IMU, simetría) sí es
reproducible.

## Ampliacion: parametros nuevos con los sensores actuales del andador

Candidatos de la literatura que usan sensores que el andador YA lleva y
cuya precision se puede corroborar con mocap. Se comprobo contra los
topics realmente grabados en los bags (no solo contra el codigo): cada bag
trae `/bwt901cl/imu` + `/imu_filtered` (IMU WitMotion, en produccion solo
alimenta la velocidad angular del EKF) y los ticks crudos
`/left_wheel`/`/right_wheel`.

| # | Parametro | Sensor real | Referencia mocap | Modulo / script |
|---|---|---|---|---|
| 1 | RMS, Harmonic Ratio (Moe-Nilssen 1998), regularidad de paso/zancada Ad1/Ad2 (Moe-Nilssen & Helbostad 2004) | IMU del chasis (`/bwt901cl/imu_filtered`) | 2a derivada de `rigid_bodies[0]` | `imu_metrics.py`, `compute_imu_stability_metrics.py` |
| 2 | Symmetry Index (Robinson 1987) de fuerza en manetas vs asimetria cinematica de paso | `/left_handle`, `/right_handle` calibrados | SpT/SdT/SpL/SdL izq-dcha de `compute_gait_from_mocap.py` | `extra_metrics.symmetry_index`, `compute_handle_symmetry_vs_gait.py` |
| 5 | Correlacion inclinacion sagital de tronco vs margen de estabilidad lateral | (ninguno nuevo) | dos parametros ya calculados | `compute_lean_vs_margin_correlation.py` |
| 3 | Validacion de `walker_stability.py` (`/user_stability`) vs margen mocap | -- | -- | **bloqueado**, ver abajo |

(El candidato 4, auditar los encoders de rueda crudos, se descarto por
decision del usuario.)

**Se aprendio por el camino (bugs propios, ya corregidos):**
- Derivar mocap dos veces sobre sus timestamps reales NO funciona: el dt
  de `rigid_bodies` es irregular (mediana ~8.3 ms, pero con valores desde
  ~0.06 ms hasta ~80 ms), y dividir por ese dt casi nulo daba RMS de ~60
  m/s2 frente a ~0.5 del IMU. Solucion en `imu_metrics.walker_accel_ap_ml`:
  remuestrear a rejilla uniforme (60 Hz) -> media movil -> 2a derivada
  centrada de 3 puntos con dt constante.
- El Symmetry Index por muestra es inestable: la calibracion de maneta
  extrapola y da kg ligeramente negativos cerca de carga nula, con lo que
  el SI sale negativo o enorme. Para el escalar por bag se calcula el SI
  sobre la fuerza MEDIA de cada lado; para la serie por muestra
  (`handle_force_symmetry_series`) se recorta a kg>=0 y el SI es NaN si
  L+R < 0.5 kg.
- `autocorr_regularity` usa normalizacion sesgada (N en el denominador,
  N-lag en el numerador): para una señal perfectamente periodica el maximo
  teorico es (N-lag)/N < 1, no exactamente 1.

**Resultados (47 bags; IMU: 46/47, `MT_test11` sin muestras de IMU en la
ventana `/tag`):**
- IMU vs mocap: RMS_AP del mismo orden en ambas fuentes (tipicamente
  0.2-0.6 m/s2); HR y Ad1/Ad2 de la misma escala pero con mucha dispersion
  bag a bag. Excepcion conocida: `MF_test06` (RMS_AP mocap 3.2 vs IMU 0.4),
  un salto de tracking mocap que sobrevive al suavizado. El IMU esta en el
  chasis del andador, no en el tronco del usuario: los valores absolutos no
  son comparables con normas de la literatura (que usan tronco). El eje V
  del IMU incluye la gravedad (~9.8 m/s2); solo se compara AP/ML (el
  chasis apenas se mueve en z, no hay V fiable en mocap).
- Simetria por maneta: SI de maneta ~190% en el sujeto CA (carga muy
  asimetrica), 1-60% en el resto. Correlacion con la asimetria cinematica
  debil (|r| < 0.62 por sujeto, |r| < 0.16 en TOTAL): son manifestaciones
  parcialmente independientes de la asimetria; resultado honesto, no un
  fallo del metodo.
- Inclinacion vs margen lateral: r = -0.475 (CA), -0.298 (LA), -0.240
  (MF), +0.002 (MT), TOTAL -0.033. Ojo: la literatura (andadores
  instrumentados) habla del margen ANTERO-POSTERIOR, no del lateral que
  calcula `posture_metrics`; es una prueba indirecta de la hipotesis.

### Punto 3 bloqueado: `walker_stability.py`

Dos bloqueos, verificados contra el codigo y contra el contenido de los bags:
1. **Bug de aridad**: `centroid_callback()` llamaba a `get_bos_x()` con 5
   argumentos y el metodo acepta 4 (`TypeError` en cada mensaje de
   centroide). Corregido quitando el argumento sobrante `self.handle_x`
   (`handle_z` es la altura de maneta que espera `handlebar_height_m`).
2. **Frames TF ausentes**: el nodo hace `lookup_transform(base_footprint,
   left_handle_id / right_handle_id)`, y `/tf_static` de los bags solo trae
   `base_link`, `laser`, `wheel_left/right`, `witmotion`, `camera_*`. Con
   estos datos el nodo no puede calcular nada ni arreglado el bug 1. No se
   invento ningun TF para forzarlo: habria metido supuestos no verificables
   sobre la geometria de las manetas. Necesita que el robot real emita esos
   frames al grabar. Trabajo posterior de `walker_stability` va en un hilo
   aparte.

### CSV de las series nuevas

`python3 scripts/export_bag_timeseries.py --bags-dir $DATASETS --out-dir DIR --ampliacion-only`
(sin replay, solo lectura de bag; tambien se generan en la ejecucion normal).
Mismo eje `t_s` (segundos desde el primer `/tag`) que el resto de CSV:

| CSV | Columnas | Notas |
|---|---|---|
| `{bag}_imu_real_accel.csv` | `t_s, ap_m_s2, ml_m_s2, v_m_s2` | crudo, sin remuestrear; asume x=AP, y=ML, z=V (montaje no verificado fisicamente); incluye gravedad |
| `{bag}_mocap_walker_accel.csv` | `t_s, ap_m_s2, ml_m_s2` | rejilla uniforme 60 Hz |
| `{bag}_mocap_handle_symmetry.csv` | `t_s, left_kg, right_kg, si_pct` | kg>=0; `si_pct`=NaN si L+R<0.5 kg |

### Autotests nuevos

`scripts/selftest_imu_metrics.py` (RMS, HR, autocorrelacion, aceleracion
AP/ML sintetica) y `scripts/selftest_correlation_utils.py`.

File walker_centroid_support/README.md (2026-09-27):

# walker_centroid_support

Estima el centro de gravedad (centroide de apoyo) del usuario sobre el
andador, siguiendo el método de J. Ballesteros (IROS 2018), combinando la
carga soportada en cada pierna y en cada maneta con la posición de esos
cuatro puntos de apoyo.

Este paquete no mide nada por sí mismo: consume las salidas ya calibradas
de [`walker_loads`](../walker_loads) (carga en kg por pierna y por maneta)
y las posiciones/TFs que publican `walker_step_detector` y
`walker_description`. Es, esencialmente, una media ponderada por peso de
cuatro posiciones.

## Cómo funciona

En cada punto de apoyo hay una carga (kg) y una posición (m, en el frame de
los pies, normalmente `base_link`):

| Punto de apoyo | Carga | Posición |
|---|---|---|
| Pie derecho | `right_leg_load` (de `/right_loads`) | `position` del propio mensaje `StepStamped` |
| Pie izquierdo | `left_leg_load` (de `/left_loads`) | `position` del propio mensaje `StepStamped` |
| Maneta derecha  | `right_handle_weight` (de `/right_hand_loads`) | TF `right_handle` → frame de los pies (ver abajo) |
| Maneta izquierda| `left_handle_weight` (de `/left_hand_loads`) | TF `left_handle` → frame de los pies (ver abajo)  |

El centroide publicado es la media ponderada de esas 4 posiciones:

```
centroide = (right_leg_load  * pos(pie_derecho)   +
             left_leg_load   * pos(pie_izquierdo) +
             right_hand_load * pos(maneta_derecha) +
             left_hand_load  * pos(maneta_izquierda)) / carga_total
```

donde `carga_total` es la suma de las cuatro cargas medidas (no el peso
declarado del usuario, ver [Decisiones de diseño](#decisiones-de-diseño)).

### Posición de las manetas

Las manetas no publican su propia posición, solo su carga. La posición se
obtiene con una consulta TF (`tf2`) entre el frame de la maneta
(`header.frame_id` del mensaje de `/left_hand_loads` / `/right_hand_loads`,
p. ej. `left_handle_id`) y el frame en el que vienen los pies (el
`header.frame_id` del propio mensaje de step, normalmente `base_link`).
Esa consulta se repite en **cada ciclo del timer**, sin cachear el
resultado, para reflejar siempre la altura de maneta actual (ver
[Decisiones de diseño](#decisiones-de-diseño)).

### Ciclo de publicación

Un timer (`period`, 20 Hz por defecto) evalúa si hay datos nuevos desde el
último ciclo (`new_data_available`, marcado por cualquiera de las 4
suscripciones de carga). Antes de publicar nada:

1. Espera a haber recibido al menos un mensaje de cada una de las 4 fuentes
   de carga (`first_data_ready`).
2. Resuelve la TF de ambas manetas; si alguna falla (aún no hay TF, o el
   frame no existe), se salta ese ciclo y se reintenta en el siguiente.
3. Si la carga total medida es ≤ 0 (todavía no hay carga real, p.ej. nada
   más arrancar), también se salta el ciclo.

Cuando las tres condiciones se cumplen, publica un `geometry_msgs/PointStamped`
con el `header` del mensaje de step derecho (mismo frame que los pies).

## Topics

### Suscritos

| Topic (parámetro) | Tipo | Publicado por |
|---|---|---|
| `/left_hand_loads` (`left_hand_loads_topic_name`)  | `walker_msgs/msg/ForceStamped` | `walker_loads` (`partial_loads`) |
| `/right_hand_loads` (`right_hand_loads_topic_name`)| `walker_msgs/msg/ForceStamped` | `walker_loads` (`partial_loads`) |
| `/left_loads` (`left_loads_topic_name`) | `walker_msgs/msg/StepStamped`  | `walker_loads` (`partial_loads`) |
| `/right_loads` (`right_loads_topic_name`) | `walker_msgs/msg/StepStamped`  | `walker_loads` (`partial_loads`) |

`ForceStamped.force` en `/left_hand_loads` y `/right_hand_loads` ya viene
calibrado en kg (no es la lectura cruda del sensor); `StepStamped.load` en
`/left_loads`/`/right_loads` ya viene repartido entre piernas según la
lógica de `partial_loads` (Kalman de diferencia de velocidad + reparto
suave). Este nodo no vuelve a calibrar ni a repartir nada, solo pondera y
combina.

Además usa `tf2` (vía `tf2_ros.Buffer`/`TransformListener`) para resolver
la posición de las manetas; no hay un parámetro de topic para esto, es la
infraestructura TF estándar (necesita que `walker_description`'s
`handle_tf_publisher` esté publicando la TF `<frame de los pies> ->
{left,right}_handle_id`).

### Publicados

| Topic (parámetro) | Tipo |
|---|---|
| `/support_centroid` (`centroid_topic_name`) | `geometry_msgs/msg/PointStamped` |

## Parámetros

| Parámetro | Por defecto | Descripción |
|---|---|---|
| `left_hand_loads_topic_name` | `/left_hand_loads`  | Carga (kg) de la maneta izquierda, ya calibrada |
| `right_hand_loads_topic_name`  | `/right_hand_loads` | Carga (kg) de la maneta derecha, ya calibrada |
| `left_loads_topic_name` | `/left_loads` | Posición + carga (kg) del pie izquierdo |
| `right_loads_topic_name` | `/right_loads` | Posición + carga (kg) del pie derecho |
| `centroid_topic_name` | `/support_centroid` | Topic de salida del centroide |
| `period` | `0.05` (20 Hz) | Periodo del timer de cálculo/publicación |

Este nodo **no** tiene parámetro de `user_desc`: no necesita el peso
declarado del usuario, ver más abajo.

## Cómo reproducir su uso

Este paquete no funciona solo; necesita el resto del pipeline de carga y
la TF de las manetas ya en marcha:

1. **`walker_loads`** (`partial_loads`, C++): necesita `/left_handle`,
   `/right_handle` (fuerza cruda, `ForceStamped`, de `walker_arduino`),
   `/detected_step_left`, `/detected_step_right` (de
   `walker_step_detector`) y `/user_desc` (`walker_msgs/msg/UserDesc`, el
   peso declarado del usuario). Publica `/left_loads`, `/right_loads`
   (carga por pierna) y `/left_hand_loads`, `/right_hand_loads` (carga por
   maneta, calibrada).
2. **`walker_description`** (`handle_tf_publisher`): publica la TF
   `<frame de los pies> -> {left,right}_handle_id`, imprescindible para que
   este nodo sepa dónde están las manetas.
3. **`walker_centroid_support`** (este paquete): lanzar
   [`centroid_support.launch.py`](launch/centroid_support.launch.py) una
   vez lo anterior esté publicando.

```bash
ros2 launch walker_loads partial_loads.launch.py
ros2 run walker_description handle_tf_publisher.py
ros2 launch walker_centroid_support centroid_support.launch.py
```

## Decisiones de diseño

- **Normaliza por la carga total medida, no por el peso declarado
  (`/user_desc`).** `right_leg_load + left_leg_load` en `partial_loads` se
  calcula como `weight - hand_loads`, recortado a `[0, weight]` para
  absorber ruido/desajustes de calibración de las manetas. Cuando ese
  recorte no actúa, dividir por la carga medida o por el peso declarado da
  exactamente el mismo resultado; cuando sí actúa, dividir por lo
  realmente medido mantiene el centroide como un baricentro autoconsistente
  (los pesos siempre suman 1) en vez de desviarlo silenciosamente. Como
  consecuencia, este nodo **no necesita `/user_desc` en absoluto**.
- **La TF de las manetas se resuelve en cada ciclo, sin caché.** Las
  manetas están fijas al andador, pero su altura (`handle_height`) puede
  cambiarse en caliente desde `handle_tf_publisher`. Cachear la TF la
  primera vez (como hacía una versión anterior de este nodo) dejaría el
  centroide calculado con una altura de maneta obsoleta si se cambia
  después de arrancar.
- **El despacho izquierda/derecha es por topic, no por `frame_id`.** Cada
  lado tiene su propia suscripción y su propio callback
  (`left_hand_load_callback`/`right_hand_load_callback`,
  `left_load_callback`/`right_load_callback`), en vez de mirar si
  `'left'`/`'right'` aparece como substring en `header.frame_id` del
  mensaje (patrón usado en otras partes de WalKit, más frágil ante un
  renombrado de frames).

## Estructura del paquete

```
walker_centroid_support/
├── launch/
│   └── centroid_support.launch.py   # lanza el nodo con los topics/periodo por defecto
├── walker_centroid_support/
│   └── centroid_support.py          # nodo CentroidSupport
└── test/                            # copyright / flake8 / pep257 (ament lint)
```

## Tests

```bash
colcon test --packages-select walker_centroid_support
```

Corre los linters estándar de ROS 2 (`ament_copyright`, `ament_flake8`,
`ament_pep257`); no hay tests funcionales del cálculo del centroide.

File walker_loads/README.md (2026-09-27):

# walker_loads

Splits the walker user's body weight between the two legs and the two handles
of the rollator, combining:

- handle force readings (calibrated to kg via a spline, see `config/handle_calib.yaml`),
- foot position/speed from `walker_step_detector`,
- the user's declared weight (`/user_desc`),

into a per-leg load estimate (`/left_loads`, `/right_loads`) and a
calibrated per-handle load (`/left_hand_loads`, `/right_hand_loads`).

## Node: `partial_loads` (C++)

### Topics

| Direction | Topic (param) | Type | Notes |
|---|---|---|---|
| sub | `left_handle_topic_name` (`/left_handle`) | `walker_msgs/ForceStamped` | raw gauge reading |
| sub | `right_handle_topic_name` (`/right_handle`) | `walker_msgs/ForceStamped` | raw gauge reading |
| sub | `left_steps_topic_name` (`/detected_step_left`) | `walker_msgs/StepStamped` | from `walker_step_detector` |
| sub | `right_steps_topic_name` (`/detected_step_right`) | `walker_msgs/StepStamped` | from `walker_step_detector` |
| sub | `user_desc_topic_name` (`/user_desc`) | `walker_msgs/UserDesc` | published **once, latched** (`transient_local`) — see below |
| pub | `left_loads_topic_name` (`/left_loads`) | `walker_msgs/StepStamped` | input step message with `.load` filled in |
| pub | `right_loads_topic_name` (`/right_loads`) | `walker_msgs/StepStamped` | input step message with `.load` filled in |
| pub | `left_hand_loads_topic_name` (`/left_hand_loads`) | `walker_msgs/ForceStamped` | gauge reading converted to kg |
| pub | `right_hand_loads_topic_name` (`/right_hand_loads`) | `walker_msgs/ForceStamped` | gauge reading converted to kg |

`/user_desc` is a one-shot config value (like a parameter set once from the
web GUI), not a continuous stream, so the node subscribes to it with a
`transient_local`/`reliable` QoS: this is what lets it still pick up the
profile if it (re)starts *after* the GUI already published it, as long as
the GUI's own publisher (or whatever republished it) is still alive to
retain the sample.

### Parameters

**Topic names**: `scan_topic`, `left_loads_topic_name`, `right_loads_topic_name`,
`left_hand_loads_topic_name`, `right_hand_loads_topic_name`,
`left_handle_topic_name`, `right_handle_topic_name`, `left_steps_topic_name`,
`right_steps_topic_name`, `user_desc_topic_name`, `handle_calibration_file`
(defaults: see table above; `handle_calibration_file` defaults to
`config/handle_calib.yaml` inside this package's share directory).

| Parameter | Default | Meaning |
|---|---|---|
| `ms_period` | 500 | Period (ms) of the timer that computes and publishes the leg-load split. |
| `debug_output` | false | Sets the logger to DEBUG and enables `DiffTracker`'s CSV dump (`diff_tracker_measurements.csv`, written to the node's working directory) — see [Debugging the Kalman tracker](#debugging-the-kalman-tracker). |
| `data_timeout_s` | 1.0 | A stream (handle force, step) not received for longer than this is treated as **no data**, not as "the last value it ever sent" — the leg-load computation pauses rather than freezing on stale input. Must be kept above `2 * ms_period/1000`, or inputs may be flagged stale between successive timer ticks (a startup warning fires if not). Does not apply to `/user_desc`: see above. |
| `speed_delta` | 0.05 | Floor (m/s) for the double-support ramp half-width (see below); also the sole threshold when `speed_delta_ratio` scaling can't apply yet. |
| `speed_delta_ratio` | 0.3 | Fraction of the estimated swing-speed amplitude (`DiffTracker::get_speed_amplitude()`) used as the double-support ramp half-width, instead of one fixed value for every user. |
| `speed_delta_max` | 1.0 | Ceiling (m/s) on that same ramp half-width — protects against the amplitude estimate spiking on bad upstream data (see [Known limitations](#known-limitations)). |
| `kalman_v0`, `kalman_va`, `kalman_vb` | 0.01, 1.0, 0.0 (m/s) | Initial speed-diff state: DC offset, in-phase and quadrature components. |
| `kalman_f0`, `kalman_fa`, `kalman_fb` | 4.0, 15.0, 0.0 (kg) | Initial force-diff state, same layout. |
| `kalman_w` | 2.0 (rad/s) | Initial shared gait angular frequency (~3 s/cycle). |
| `kalman_theta` | 0.20 (rad) | Initial absolute phase. |
| `w_estimate_min`, `w_estimate_max` | 0.3, 8.0 (rad/s) | Plausible range for a gait-cycle frequency measured from step-alternation timing (~20 s down to ~0.8 s per cycle); estimates outside this range are dropped. |
| `zero_crossing_refractory_s` | 0.2 | Minimum time between accepted zero-crossings of the L/R speed difference, so sensor noise wobbling around zero isn't mistaken for a stance/swing swap. |

All the `kalman_*` values and the noise covariances inside `DiffTracker` are
physically-reasoned starting points, not values fitted against real data —
see [Known limitations](#known-limitations).

## How the leg-load split works

1. `leg_load = weight - left_hand_force - right_hand_force`, clamped to
   `[0, weight]` (a noisy or out-of-calibration-range handle reading must
   never produce a negative or over-100% load; `SplineFunction::interp()`
   itself also clamps to the calibrated force range instead of
   extrapolating past it).
2. The user is assumed to be either fully on one leg (single support) or
   sharing the load between both (double support). Instead of a hard
   threshold on the left/right foot speed difference — which jumps straight
   from 50/50 to 100/0 the instant it's crossed, and chatters when the
   speed difference is noisy near it — the split ramps smoothly across a
   band `[-band, +band]` around zero:
   `right_fraction = 0.5 * (1 + clamp(speed_diff / band, -1, 1))`.
3. `band` scales with how big this user's actual swing/stance speed gap is
   (`speed_delta_ratio * amplitude`, floored at `speed_delta` and capped at
   `speed_delta_max`) instead of one fixed number for every user — a slow
   walker's speed difference would otherwise never reach a one-size-fits-all
   threshold, and a fast walker's would blow past it immediately.
4. `speed_diff` and `amplitude` both come from `DiffTracker`, a Kalman
   filter over the left/right speed and force differences — see below.

## The Kalman tracker (`DiffTracker`)

`DiffTracker` models the left/right speed-diff and force-diff signals as two
sinusoids sharing one gait frequency `w` and absolute phase `theta`:

```
speed_diff(t) = v0 + va*sin(theta) + vb*cos(theta)
force_diff(t) = f0 + fa*sin(theta) + fb*cos(theta)
theta_k+1 = theta_k + w*dt
```

State: `[v0, va, vb, f0, fa, fb, w, theta]` (`kalman/DiffSystemModel.hpp`).

### Why Cartesian (va,vb), not amplitude+phase

An earlier version tracked amplitude (`v1`/`f1`) and phase directly, i.e.
`speed_diff = v0 + v1*sin(phase)`. That is a *polar* parameterization of the
same sinusoid, and polar coordinates have a singularity at the origin: the
measurement's sensitivity to `v1` is exactly `sin(phase)`, which vanishes
whenever the signal is near zero — at that point an arbitrarily large `v1`
paired with a near-zero `sin(phase)` explains the data exactly as well as
the correct, small `v1`. On real (if imperfect) offline replay data this
made the estimated amplitude settle on stable but physically nonsensical
values (~100, two orders of magnitude above a plausible gait speed). The
Cartesian form removes that: the measurement Jacobian for `(va,vb)` is
`(sin(theta), cos(theta))`, and `sin²+cos²=1` always, so it's never
simultaneously blind to both. Amplitude/phase, when needed, are derived
(`amplitude = sqrt(va²+vb²)`) rather than tracked directly. This also drops
the old model's separate force/speed delay parameter `d`: it's now implicit
in how `(fa,fb)` relate to `(va,vb)` at the same `theta`.

### Why `w` is measured, not just estimated

Neither the speed nor the force measurement has any Jacobian sensitivity to
`w` (see `updateJacobians()` in `SpeedMeasurementModel.hpp` /
`ForceMeasurementModel.hpp`) — it can only move through weak, indirect
coupling via `theta`. In practice this let `w` drift toward zero, which
stalls `theta`'s rotation and reintroduces the same amplitude degeneracy the
Cartesian form was meant to fix (if `theta` barely moves, every measurement
constrains the same one direction in the `(va,vb)` plane, and the
orthogonal one is free to grow).

`PartialLoads::update_gait_frequency()` fixes this by measuring `w`
directly: a zero-crossing of the L/R speed difference marks the moment the
swing/stance roles swap, which happens twice per gait cycle, so the time
between two consecutive crossings is half a gait period
(`w = pi / half_period`, validated against `[w_estimate_min, w_estimate_max]`
before being fed in). This is `DiffTracker::add_frequency_measurement()`,
backed by a dedicated linear measurement model
(`kalman/FrequencyMeasurementModel.hpp`, `h(x) = w`) with a real, unambiguous
Jacobian — unlike speed/force, this one really does observe `w` directly.

### Why speed/force updates can't touch `w` (`partialUpdate()`)

Even with a direct frequency channel, it fires only once per half gait-cycle
while the speed/force updates fire far more often and, despite having zero
*direct* sensitivity to `w`, still perturb it through the covariance's
`w`-`theta` cross term built up in every `predict()` step. Two tuning
attempts confirmed this empirically before landing on the real fix:

- **A floor/ceiling on `w`** (`clampFrequency()`) stopped it collapsing to
  zero, but the indirect drag between corrections still made the amplitude
  spike into the tens/hundreds.
- **Tightening the process noise `Q(W,W)`** to resist that drag backfired:
  it also weakened the Kalman gain of the rare, *good* direct corrections
  (both route through the same `P(W,W)`), so `w` spent *more* time pinned
  at the floor, not less.

The actual fix: `add_speed_measurement()`/`add_force_measurement()` now go
through `DiffTracker::partialUpdate()`, which performs the same update math
as `Kalman::ExtendedKalmanFilter::update()` but forces the `w` component of
the Kalman gain to zero and explicitly restores `w`'s row *and* column of
the covariance matrix afterward (zeroing the gain alone only protects the
row; the column can still leak through the other states' own gains).  Only
`add_frequency_measurement()` still goes through the library's normal,
unmasked update, and is the only thing allowed to move `w`. This required
one small addition to the vendored `kalman/` headers:
`LinearizedMeasurementModel::computeJacobian()`, which exposes the model's
`H` (otherwise `protected`, only usable by `ExtendedKalmanFilter` itself)
so `partialUpdate()` doesn't have to duplicate each model's Jacobian
formula by hand.

`clampFrequency()` is kept as a cheap backstop (e.g. before the first
frequency measurement ever arrives) even though it should now rarely, if
ever, trigger.

## Reproducing / testing this offline

`launch/replay_offline.launch.py` replays a labeled rosbag (from
`soma13kp/datasets/labeled_bags`, e.g. `MF_test05`) that is missing
`/user_desc`, `/handle_height` and part of the walker's tf tree, and
reconstructs them from `bagsFolder_unified/test_config.txt`:

```bash
ros2 launch walker_loads replay_offline.launch.py \
    bag_path:=/path/to/soma13kp/datasets/labeled_bags/MF_test05 \
    rate:=3.0
```

It brings up the walker's static tf tree (`walker_description`), the handle
tf (from the bag's configured `handle_height`), `walker_step_detector`
(`km_detect_steps`) and `partial_loads` itself, then plays back only the
topics needed (`/left_handle`, `/right_handle`, `/scan_filtered`, `/tf`,
`/tf_static`). See the file's own docstring for the exact field mapping from
`test_config.txt`.

### Debugging the Kalman tracker

Set `debug_output:=true` on `partial_loads` (e.g. edit
`launch/partial_loads.launch.py`) to write
`diff_tracker_measurements.csv` (in the node's working directory) on every
`predict`+`update`: raw measurement (`sp_m`/`fo_m`/`fw_m`, whichever of the
three fired that row), the tracker's own prediction (`sp_pred`/`fo_pred`),
and the full state (`amp`, `va`, `vb`, `w`, `theta`). Useful for checking
`w`/`amp` actually hold steady between corrections instead of drifting.

## Known limitations

- The Kalman noise covariances (`configureNoise()` in `diff_tracker.cpp`)
  and the `kalman_*` priors are physically-reasoned starting points, not
  values fitted against real data — retune once `walker_step_detector`
  gives trustworthy step speeds to validate against.
- The estimated amplitude still reflects some of `walker_step_detector`'s
  own known noise, not purely the user's real gait — `speed_delta_max`
  bounds how much that can affect the leg-load ramp, but doesn't fix the
  upstream signal.
- `theta` isn't re-wrapped to `[0, 2*pi)` after a measurement update (only
  `SystemModel::f()`'s own prediction step wraps it) — harmless since
  `sin`/`cos` are periodic regardless, and it self-corrects at the next
  `predict()`, but worth knowing if you inspect the debug CSV directly.

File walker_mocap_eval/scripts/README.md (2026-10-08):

# scripts/ — orden de ejecución

Todos estos scripts son Python plano (no forman parte del build de
colcon). Antes de ejecutar cualquiera, desde una terminal nueva:

```bash
source /opt/ros/jazzy/setup.bash
source /home/mfcarmona/workspace/walker_ws/install/setup.bash
cd WalKit/walker_mocap_eval
```

`$DATASETS` en los ejemplos = `/home/mfcarmona/workspace/walker_ws/src/soma13kp/datasets/labeled_bags`
(47 bags etiquetados, 4 sujetos: `CA`, `LA`, `MF`, `MT`).

## 0. Autotests (opcional, sin bags)

Validan la lógica portada con datos sintéticos, antes de tocar bags reales:

```bash
python3 scripts/selftest_gait_metrics.py
python3 scripts/selftest_posture_metrics.py
python3 scripts/selftest_cog_estimation.py
python3 scripts/selftest_imu_metrics.py
python3 scripts/selftest_correlation_utils.py
```

## 1. Cálculo de métricas desde mocap (4 scripts independientes)

Cada uno lee los bags etiquetados directamente (sin reproducir nada) y
escribe un JSON con un registro por bag. Se pueden correr en cualquier
orden / en paralelo.

```bash
python3 scripts/compute_gait_from_mocap.py \
    --bags-dir $DATASETS --out /tmp/report_gait_mocap.json
# Punto 1: SpT/SdT/SpL/SdL por pierna, NoS, Tr, d, CAD, WV

python3 scripts/compute_posture_from_mocap.py \
    --bags-dir $DATASETS --out /tmp/report_posture_mocap.json
# Inclinación de tronco, ancho de paso, doble apoyo, margen de estabilidad lateral

python3 scripts/compute_cog_from_mocap.py \
    --bags-dir $DATASETS --out /tmp/report_cog_mocap.json
# Punto 3: centro de gravedad (modelo De Leva 1996), requiere test_config.txt
# (peso/altura/sexo por bag; por defecto ~/bagsFolder_unified/test_config.txt)

python3 scripts/compute_extra_metrics_from_mocap.py \
    --bags-dir $DATASETS --out /tmp/report_extra_mocap.json
# Codo, muñeca, reparto de peso en manetas, yaw/curvatura, oscilación
# vertical del CoM, índice de inestabilidad (puntos 3-elbow/4/5/8/9/11)
```

Flags comunes: `--bag <dir>` para un único bag en vez de `--bags-dir`,
`--ignore-tags` para NO recortar a la ventana `/tag` (por defecto SÍ se
recorta — ver `readme.md` del paquete).

## 2. Exportar series temporales completas (el único paso que reproduce bags)

```bash
python3 scripts/export_bag_timeseries.py \
    --bags-dir $DATASETS --out-dir /tmp/report_timeseries
```

Para cada bag: calcula las series de mocap directamente (sin reproducir),
y hace **una única reproducción** del pipeline real completo
(`box_filter` → `detect_steps` → `partial_loads` → `mocap_odom_bridge` →
`gait_monitor_speed` + `walker_centroid_support`) grabando todo lo que
publica. Escribe un CSV por serie y por fuente
(`{bag}_mocap_*.csv`, `{bag}_walker_*.csv`), todas con el mismo eje
temporal `t_s` (segundos desde el inicio del bag) para poder graficar
mocap y andador juntos. Usa `ROS_DOMAIN_ID` propio internamente para no
interferir con otros procesos ROS en la máquina.

Tarda bastante sobre los 47 bags (hay que reproducir cada uno en tiempo
real/`--rate`); usarlo en background. `--mocap-only` salta la
reproducción si solo hacen falta las series de mocap. `--limit N` para
probar sobre los N primeros bags antes de lanzar los 47.

## 3. Derivar comparación mocap-vs-andador (punto 2 + CoG) desde los CSV

No reproduce nada: relee los CSV del paso 2 y el JSON del paso 1 para
calcular errores (MAE/MedAE/Bias/RMSE/MAPE — fórmulas en el informe).

```bash
python3 scripts/derive_comparison_metrics.py \
    --bags-dir $DATASETS \
    --timeseries-dir /tmp/report_timeseries \
    --gait-json /tmp/report_gait_mocap.json \
    --out-json /tmp/report_comparison.json \
    --out-csv-dir /tmp/report_timeseries
```

Solo se usan filas del andador con `t_s` <= fin de la ventana `/tag`:
`export_bag_timeseries.py` graba unos segundos más allá del segundo `/tag`
(espera `duración/rate + 3 s`) y ese tramo, con el usuario ya parado, no
corresponde a lo que mide mocap. Además de MAE/MedAE/Bias/RMSE/MAPE se
calcula MedAPE (mediana del error porcentual), robusta a los pocos bags con
errores enormes; el informe añade filas de mediana por sujeto y TOTAL.

Añade además `{bag}_cog_comparison.csv` a `--out-csv-dir` (mocap vs
`/support_centroid` muestra a muestra). Nota: solo el plano `x`/`y` del
CoG es comparable con el centroide de soporte real — `z` y la distancia
3D se calculan pero se marcan como no comparables (ver `§2.7` del informe:
son dos magnitudes físicas distintas, no el mismo punto en otro frame).

## 3b. Ampliación: 3 scripts adicionales (sin reproducir bags)

Nuevos parámetros candidatos de la literatura, con los sensores que el
andador ya lleva (ver `§10` del informe). Se pueden correr en paralelo
entre sí y en cualquier momento después del paso 1 (necesitan sus JSON).

```bash
python3 scripts/compute_imu_stability_metrics.py \
    --bags-dir $DATASETS --gait-json /tmp/report_gait_mocap.json \
    --out /tmp/report_imu_mocap.json
# Punto 1 ampliación: Harmonic Ratio / RMS / regularidad por autocorrelación,
# IMU real del andador (/bwt901cl/imu_filtered) vs equivalente por mocap

python3 scripts/compute_handle_symmetry_vs_gait.py \
    --extra-json /tmp/report_extra_mocap.json --gait-json /tmp/report_gait_mocap.json \
    --out /tmp/report_handle_symmetry.json
# Punto 2 ampliación: Symmetry Index de fuerza en manetas (sensor real) vs
# asimetría cinemática de paso (mocap) -- post-procesa JSON ya calculados,
# no lee bags

python3 scripts/compute_lean_vs_margin_correlation.py \
    --posture-json /tmp/report_posture_mocap.json \
    --out /tmp/report_lean_vs_margin.json
# Punto 5 ampliación: correlación inclinación de tronco vs margen de
# estabilidad lateral -- sin sensor nuevo, post-procesa JSON ya calculado
```

(El punto 3 de la ampliación, validación de `walker_stability.py`, quedó
bloqueado por un bug real del nodo y por frames TF ausentes en los bags —
no tiene script propio, ver `§10.4` del informe.)

## 4. Fusionar todo en un master JSON por bag

```bash
python3 scripts/build_master_report_data.py \
    --gait /tmp/report_gait_mocap.json \
    --posture /tmp/report_posture_mocap.json \
    --cog /tmp/report_cog_mocap.json \
    --extra /tmp/report_extra_mocap.json \
    --comparison /tmp/report_comparison.json \
    --imu /tmp/report_imu_mocap.json \
    --handle-symmetry /tmp/report_handle_symmetry.json \
    --lean-vs-margin /tmp/report_lean_vs_margin.json \
    --out /tmp/report_master.json \
    --out-csv /tmp/report_timeseries/master_per_bag_summary.csv
```

No recalcula nada: solo junta los JSON de los pasos 1, 3 y 3b en un único
registro por bag (y opcionalmente una tabla plana en CSV para abrir en
una hoja de cálculo). `--imu`/`--handle-symmetry`/`--lean-vs-margin` son
opcionales (se omiten si no se han corrido los scripts de la ampliación).

## 5. Generar el informe LaTeX

```bash
python3 scripts/generate_latex_report.py \
    --master /tmp/report_master.json --out /tmp/informe/informe.tex
cd /tmp/informe && pdflatex -interaction=nonstopmode informe.tex && pdflatex -interaction=nonstopmode informe.tex
```

(`pdflatex` se ejecuta dos veces: la primera resuelve el contenido, la
segunda arregla referencias cruzadas/índice). Las tablas desglosan las 47
repeticiones y agregan **por sujeto** (`CA`/`LA`/`MF`/`MT`, no una única
media de los 47 bags) más una fila TOTAL de referencia.

**Repetibilidad del replay (limitación abierta).** La reproducción del lado
andador no es determinista: a rate 4, `partial_loads` decide qué pierna
carga con un temporizador de reloj de pared, y el resultado depende de
dónde cae cada decisión en el bag (y de la carga de CPU). Dos ejecuciones
dieron MAPE del SpT izquierdo de 38% (30 sep-1 oct 2026) y 58% (6 oct 2026).
Todas las cifras del lado andador del informe son de **una sola ejecución,
la de octubre de 2026**, y las cifras escritas a mano en el texto de
`generate_latex_report.py` (literatura, limitaciones, conclusiones) hay que
revisarlas si se repite el replay; las tablas sí se recalculan. No está
cuantificada la variabilidad entre repeticiones. Lo calculado solo desde
mocap o sensores grabados (marcha mocap, postura, IMU, simetría) sí es
reproducible.

## Resumen del flujo

```
                 (paso 1, 4 scripts, sin reproducir bags)
labeled_bags/ --> compute_gait_from_mocap.py       --> report_gait_mocap.json      --\
             \--> compute_posture_from_mocap.py     --> report_posture_mocap.json   --\
             \--> compute_cog_from_mocap.py         --> report_cog_mocap.json       ---+--> build_master_report_data.py --> report_master.json --> generate_latex_report.py --> informe.tex --> informe.pdf
             \--> compute_extra_metrics_from_mocap.py -> report_extra_mocap.json    --/
             \
              \--> export_bag_timeseries.py (reproduce cada bag 1 vez)
                   --> report_timeseries/*.csv --> derive_comparison_metrics.py --> report_comparison.json --/

                 (paso 3b, ampliación -- post-procesan los JSON del paso 1, sin leer bags salvo el de IMU)
report_gait_mocap.json ------------------------> compute_imu_stability_metrics.py       --> report_imu_mocap.json       --\
report_extra_mocap.json + report_gait_mocap.json -> compute_handle_symmetry_vs_gait.py  --> report_handle_symmetry.json --+--> build_master_report_data.py
report_posture_mocap.json ---------------------> compute_lean_vs_margin_correlation.py  --> report_lean_vs_margin.json   --/
```

## Otros scripts (no forman parte del flujo anterior)

- `compare_gait_mocap_vs_walker.py`, `compare_cog_mocap_vs_walker.py`:
  versiones más antiguas que reproducen cada bag en vivo y comparan
  directamente (una reproducción por comparación, en vez de reutilizar
  los CSV de `export_bag_timeseries.py`). Se conservan como referencia /
  validación cruzada, pero el flujo recomendado es el de arriba.
- `mocap_odom_bridge.py`: nodo ROS auxiliar (no CLI de análisis) que
  republica el *rigid body* del andador en mocap como `/odom`, porque
  `/left_wheel`/`/right_wheel` reales están rotos en estos bags; lo lanza
  internamente `export_bag_timeseries.py`/`compare_*_vs_walker.py` como
  parte del pipeline de reproducción.
- `eval_odom_against_mocap.py`: evalúa una odometría grabada (por defecto
  `/odom` del EKF láser+IMU de `walker_bringup`) contra el mocap: ATE tras
  alinear con Umeyama 2D, error de rumbo y deriva en % del recorrido. Es
  la vía para validar la odometría REAL del andador, que el flujo de arriba
  NO valida: en la reproducción de `export_bag_timeseries.py` el `/odom`
  sale del propio mocap (`mocap_odom_bridge.py`), así que `d` y `WV` del
  informe solo validan la aritmética de `gait_monitor_speed`. No forma
  parte del flujo del informe; ver su docstring para qué grabar.

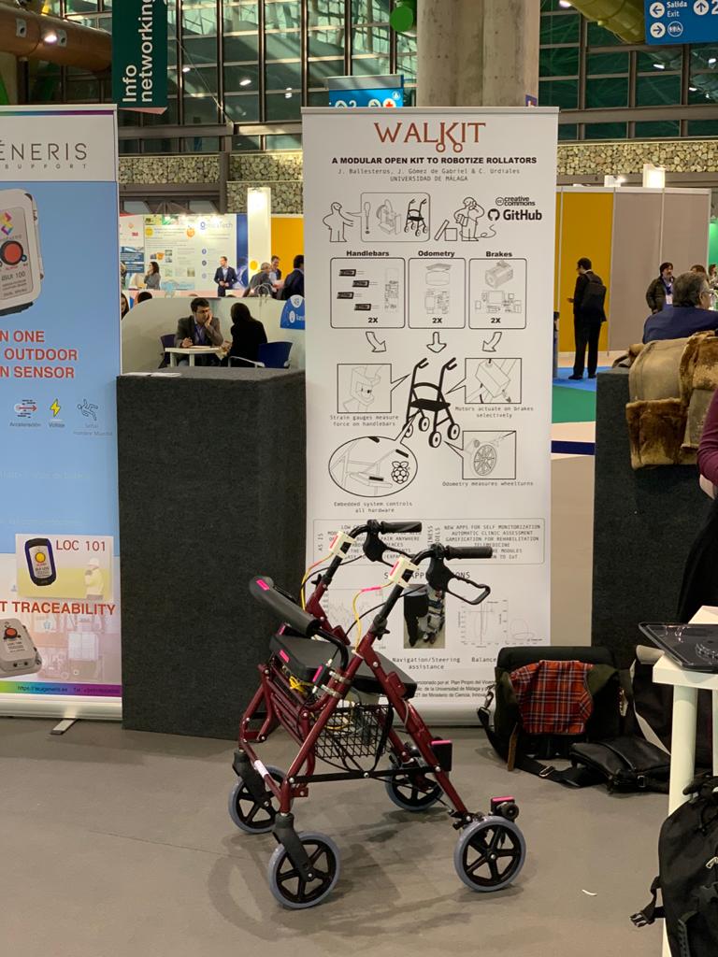
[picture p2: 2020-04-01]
Pictures/walkerTransfiere.jpg

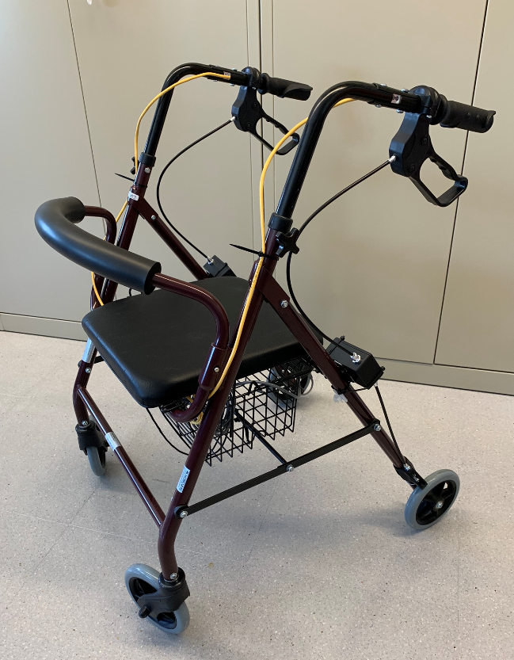
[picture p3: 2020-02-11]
Pictures/Walker.png

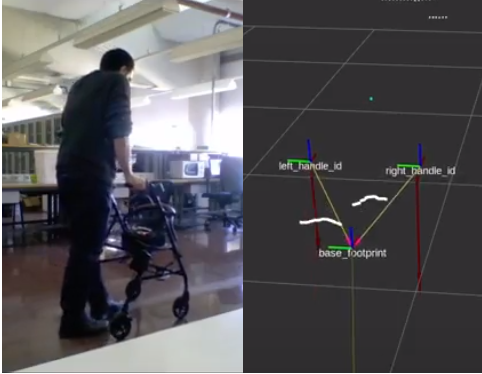
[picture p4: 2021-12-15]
Pictures/ejemplo.png

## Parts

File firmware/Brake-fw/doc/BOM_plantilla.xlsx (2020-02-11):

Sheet: BOM
 |  |  |  |  | BILL OF MATERIALS
Referencia
Nombre
Revisión |  | 0
Fecha: |  | 0
Order | Designator | QTY | Name | Value 1 | Value 2 | Package | Block | Part Num | Man. 1 | Man.1 P.N. | Man. 2 | Man. 2 P.N. | Vendor 1 | Vendor 1 P.N. | Vendor 2 | Vendor 2 P.N. | Notes
1
2
3
4
5
6
7
8
9
10
11
12
13
14
15
16
17
18
19
20
21
22
23
24
25
26
27
28
29
30
31
32
33
34
35
36
37
38
39
40
41
42

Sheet: Revisiones
 |  |  | BILL OF MATERIALS
REVISION | FECHA | HORA | CAMBIOS | AUTOR
0 |  |  | Inicio del BOM

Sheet: Leyenda
Para ampliar la tabla del BOM arrastrar la esquina inferior derecha hacia abajo. |  |  | Vers. Plantilla 1.1 | 2016-03-09
Referencia |  | Nombre del proyecto
Nombre |  | Nombre del creador
Revisión |  | Se rellena automáticamente con la pestaña de revisión (0 el inicio)
Fecha: |  | Se rellena automáticamente con la pestaña de revisión
Concepto | Descripción | Ejemplo 1 | Ejemplo 2 | Nota | Notas de uso habitual
Order | Número de orden en el BOM | 1,2,3,4…
Part Num. | Número de referencia interno de Sentecno | Por implementar |  |  | No lo solemos rellenar
Designator | Código de referencia en el esquema | R1,R2,R3,C1,C2
Name | Descripcion del componente | Condensador electrolítico |  |  | No se sigue como el ejemplo 1. Se indica el tipo de resistencia o condensador etc.
Value 1 | Valor del ítem | 20nF | 1k
Value 2 | En el caso de que haya otro valor de relevancia | 24v | 5%
Package | Encapsulado del item | C0603 | R0406
Block | Bloque de montaje | 0 | 1 | Determina el grupo en el que se ensambla el ítem. Bloque 0 para lo que siempre monta y bloques 1,2,… para el resto. Usar 0 por defecto. | Aquí estamos indicando cuando un componente no monta
Manufacturer 1 | Nombre del fabricante 1 | SAMTEC | VISHAY SILICONIX | Preferencia utilizar el fabricante del modelo definitivo
Manufacturer 1 P.N. | Referencia del fabricante 1 | IPL1-110-02-L-SH-K | SI1012CR-T1-GE3
Manufacturer 2 | Nombre del fabricante 2 |  |  | Preferencia utilizar el fabricante para prototipos en caso de ser diferente al 1 | Si hay otra referencia de fabricante alternativa que sea de interés
Manufacturer 2 P.N. | Referencia del fabricante 2 |  |  |  | Si hay otra referencia de fabricante alternativa que sea de interés
Vendor 1 | Distribuidor 1 | Mouser |  |  | No se suele rellenar.
Vendor 1 P.N. | Referencia del distribuidor 1 | 571-796636-3 |  |  | No se suele rellenar.
Vendor 2 | Distribuidor 2 | Farnell |  |  | No se suele rellenar.
Vendor 2 P.N. | Referencia del distribuidor 2 | 2018462 |  |  | No se suele rellenar.
Notes | Notas |  | La referencia 2 dió problemas en montaje porque los pads se caían. |  | Indicar cualquier nota de relevancia.

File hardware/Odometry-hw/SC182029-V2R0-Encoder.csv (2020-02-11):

Qty | Value | Device | Package | Parts | Description | BLOCK | LAYER | MAN1 | MAN1PN | MAN2 | MAN2PN | NOTES | SENTPN | VALUE2
1 | 1uF | COND_CERAMICO_SMD0603R | C0603R | C12 | Condensador ceramico SMD |  |  | Taiyo Yuden | LMK107B7105KA-T |  |  |  | CCSMD-0603R-105-16V | 16V
1 | 2.2uF | COND_CERAMICO_SMD0603R | C0603R | C13 | Condensador ceramico SMD |  |  | Taiyo Yuden | EMK107BJ225MA-T |  |  |  | CCSMD-0603R-225-10V | 10V
5 | 100nF | COND_CERAMICO_SMD0603R | C0603R | C7, C8, C9, C10, C11 | Condensador ceramico SMD |  |  | AVX | 0603YC104KAT2A |  |  |  | CCSMD-0603-104-6V3 | 6V3
1 |  | WL-SMCW-150060BS75000 | WL-SMCW_0603 | D2 | SMD mono-color Chip LED |  |  | Inolux | IN-S63AT5G |  |  |  | LEDSMD-0603-GREEN
1 | MCP2515-I/ML | MCP2515-I/ML | QFN50P400X400X90-21N | H1 | Stand-Alone CAN Controller SPI QFN20 Microchip MCP2515-E/ML, CAN Controller 1MBps CAN 2.0B, 20-Pin QFN |  |  | Microchip | MCP2515-I/ML |  |  | H0.9mm | MCP2515-I/ML
1 | ATMEGA328P-MU | ATMEGA328P-MU | QFN50P500X500X100-33N | IC1 | Programmable Flash |  |  | Microchip Technology / Atmel | ATMEGA328P-MU |  |  |  | ATMEGA328P-MU
1 | MCP2562T-H_SN | MCP2562T-H_SN | SOIC127P600X175-8N | IC4 | CAN Interface IC |  |  | Microchip | MCP2562T-H/SN |  |  | H1.75mm | MCP2562T-H/SN
1 | AP2210N-SOT23-3 | AP2210N-SOT23-3 | SOT95P280X130-3N | IC5 | DiodesZetex AP2210N, Low Noise LDO Voltage Regulator, 300mA, 2%, 2.5 13.2 Vin, 3-Pin SOT-23 |  |  | Diodes Inc. | AP2210N-5.0TRG1 |  |  | H1.3mm | AP2210N-5.0TRG1
1 | PINH-2X03-2.54-TH-M20 | PINH-2X03-2.54-TH-M20 | HDRV6W64P254_2X3_762X508X868P | JP2 |  |  |  | Harwin | M20-9980346 |  |  |  | PINH-2X03-2.54
1 | LED_TUBEH1 | LED_TUBEH1 | LED_TUBE_2 | LED_TUBE1 |  |  |  | Bivar | SLP3-150-150-F |  |  |  | SLP3-150-150-F
2 | 10K | RES_CERAMICA_SMD0603R | R0603R | R1, R2 | Resistencia ceramica SMD |  |  | Yageo | RC0603JR-074K7L |  |  |  | RSMD-0603-4K7
1 | 390R | RES_CERAMICA_SMD0603R | R0603R | R12 | Resistencia ceramica SMD |  |  | Yageo | RC0603FR-07390RL |  |  |  | RSMD-0603-390R
1 | 10K | RES_CERAMICA_SMD0603R | R0603R | R5 | Resistencia ceramica SMD |  |  | Bourns | CR0603-JW-103ELF |  |  |  | RSMD-0603-10K
1 | 120R | RES_CERAMICA_SMD0603R | R0603R | R8 | Resistencia ceramica SMD |  |  | Yageo | RC0603FR-07120RL |  |  |  | RSMD-0603R-120R-10 | 1%
1 | RJ45-PLASTIC-SMD | RJ45-PLASTIC-SMD | 73304111LF | RJ45-1 | WR-MJ Horizontal Plastic 8P8C Modular Jack Tab Down, 8 Pins=>Code : Con_I_O_MJ-H_Plastic_Down_615008137121 |  |  | Amphenol FCI | 73304-111LF |  |  | H14mm | CONSTD-RJ45-SMD-90
1 |  | DIP-SW-2 | SMD-DIP-SWITCH-2P | S1 |  |  |  | CTS Electronic Components | 219-2MST |  |  |  | SWSMD-1x02
2 | 16MHz | RESONADOR_CERAMICO-UNKN1 | CSTNE16M0V530000R0 | Y1, Y2 |  |  |  | Murata Electronics | CSTNE16M0V530000R0 |  |  | H0.9mm | CRES-3.2x1.3-16MHz

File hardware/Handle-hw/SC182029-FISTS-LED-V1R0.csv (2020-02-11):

Qty | Value | Device | Package | Parts | Description | BLOCK | LAYER | MAN1 | MAN1PN | MAN2 | MAN2PN | NOTES | SENTPN | VALUE2
1 | LED_RGB-PLCC4 | LED_RGB-PLCC4 | PLCC4 | LED | RGB LED |  |  | Cree, Inc. | CLMVB-FKA-CFHEHLCBB7a363 |  |  |  | LEDSMD-PLCC4-RGB
1 | 560R | RES_CERAMICA_SMD0603R | R0603R | R1 | Resistencia ceramica SMD |  |  | Yageo | RC0603JR-07560RL |  |  |  | RSMD-0603-560R
1 | 390R | RES_CERAMICA_SMD0603R | R0603R | R2 | Resistencia ceramica SMD |  |  | Yageo | RC0603FR-10390RL |  |  |  | RSMD-0603-390R
1 | 390R | RES_CERAMICA_SMD0603R | R0603R | R3 | Resistencia ceramica SMD |  |  | Yageo | RC0603FR-07390RL |  |  |  | RSMD-0603-390R

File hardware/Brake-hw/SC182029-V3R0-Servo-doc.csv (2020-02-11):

 |  | LISTADO DE COMPONENTES MÓDULO DE FRENOS
Qty | Value | Device | Package | Parts | Description | BLOCK | LAYER | MAN1 | MAN1PN | MAN2 | MAN2PN | NOTES | SENTPN | VALUE2
2 | 22uF | COND_PANASONIC_EEE-B | B | C1, C2 | Panasonic Aluminum Electrolytic Capacitors |  |  | Illinois Capacitor / CDE | 226SML016MD4 |  |  | H5.5mm | CESMD-PB-226-16V | 16V
1 | 1uF | COND_CERAMICO_SMD0603R | C0603R | C4 | Condensador ceramico SMD | 0 | Top | Taiyo Yuden | TMK107B7105KA-T |  |  |  | CCSMD-0603-105-25V | 25V
6 | 100nF | COND_CERAMICO_SMD0603R | C0603R | C6, C7, C8, C9, C10, C11 | Condensador ceramico SMD |  |  | AVX | 0603YC104KAT2A |  |  |  | CCSMD-0603-104-6V3 | 6V3
1 |  | WL-SMCW-150060BS75000 | WL-SMCW_0603 | D2 | SMD mono-color Chip LED |  |  | Inolux | IN-S63AT5G |  |  |  | LEDSMD-0603-GREEN
1 | MCP2515-I/ML | MCP2515-I/ML | QFN50P400X400X90-21N | H1 | Stand-Alone CAN Controller SPI QFN20 Microchip MCP2515-E/ML, CAN Controller 1MBps CAN 2.0B, 20-Pin QFN |  |  | Microchip | MCP2515-I/ML |  |  | H0.9mm | MCP2515-I/ML
1 | ATMEGA328P-MU | ATMEGA328P-MU | QFN50P500X500X100-33N | IC1 | Programmable Flash |  |  | Microchip Technology / Atmel | ATMEGA328P-MU |  |  |  | ATMEGA328P-MU
1 | MCP2562T-H_SN | MCP2562T-H_SN | SOIC127P600X175-8N | IC4 | CAN Interface IC |  |  | Microchip | MCP2562T-H/SN |  |  | H1.75mm | MCP2562T-H/SN
1 | PINH-1X03-2.54 | PINH-1X03-2.54 | PINH-1X03-2.54-1 | JP1 |  |  |  | Harwin | M20-9990346 |  |  |  | PINH-M-1x03-2.54
1 | PINH-2X03-2.54-TH-M20 | PINH-2X03-2.54-TH-M20 | HDRV6W64P254_2X3_762X508X868P | JP2 |  |  |  | Harwin | M20-9980346 |  |  |  | PINH-2X03-2.54
1 | 6.8uH | NR5040 | NR5040 | L1 |  |  |  | Taiyo Yuden | NR5040T6R8M |  |  | H4mm | NR5040T6R8M
1 | LED_TUBEH1 | LED_TUBEH1 | LED_TUBE_2 | LED_TUBE1 |  |  |  | Bivar | SLP3-150-150-F |  |  |  | SLP3-150-150-F
1 | AP65211A | AP65211A | SOT95P280X90-6N | Q3 | LIGHT LOAD IMPROVED 1.5A SYNCH DC/DC BUCK CONVERTER TSOT26 | 0 | Top | Diodes Inc. | AP65211A |  |  |  | AP65211A
1 | 75K | RES_CERAMICA_SMD0603R | R0603R | R1 | Resistencia ceramica SMD | 0 | Top | Yageo | RC0603JR-0775KL |  |  |  | RSMD-0603-75K
1 | 390R | RES_CERAMICA_SMD0603R | R0603R | R12 | Resistencia ceramica SMD |  |  | Yageo | RC0603FR-07390RL |  |  |  | RSMD-0603-390R
1 | 7K68 | RES_CERAMICA_SMD0603R | R0603R | R2 | Resistencia ceramica SMD | 0 | Top | Bourns | CR0603-FX-7681ELF | RC0603FR-077K68L | Yageo |  | RSMD-0603-7K68
1 | 40K2 | RES_CERAMICA_SMD0603R | R0603R | R3 | Resistencia ceramica SMD | 0 | Top | Yageo | RC0603FR-0740K2L |  |  |  | RSMD-0603-40K2
1 | 100K | RES_CERAMICA_SMD0603R | R0603R | R4 | Resistencia ceramica SMD | 0 | Top | Bourns | CR0603-JW-104GLF |  |  |  | RSMD-0603-100K
1 | 10K | RES_CERAMICA_SMD0603R | R0603R | R5 | Resistencia ceramica SMD |  |  | Bourns | CR0603-JW-103ELF |  |  |  | RSMD-0603-10K
1 | 120R | RES_CERAMICA_SMD0603R | R0603R | R8 | Resistencia ceramica SMD |  |  | Yageo | RC0603FR-07120RL |  |  |  | RSMD-0603R-120R-10 | 1%
1 | RJ45-PLASTIC-SMD | RJ45-PLASTIC-SMD | 73304111LF | RJ45-1 | WR-MJ Horizontal Plastic 8P8C Modular Jack Tab Down, 8 Pins=>Code : Con_I_O_MJ-H_Plastic_Down_615008137121 |  |  | Amphenol FCI | 73304-111LF |  |  | H14mm | CONSTD-RJ45-SMD-90
1 | 0.1R | RES_CERAMICA_SMD0603R | R0603R | RSENS | Resistencia ceramica SMD |  |  | Yageo | RL0603JR-070R1L |  |  |  | RSMD-0603-0R1
1 |  | DIP-SW-2 | SMD-DIP-SWITCH-2P | S1 |  |  |  | CTS Electronic Components | 219-2MST |  |  |  | SWSMD-1x02
1 | INA181A1IDBVR | INA181A1IDBVR | SOT95P280X145-6N | U1 | Current Sense Amplifiers 26V, Bidirectional, Low- or High-Side Voltage Output Current Sense Amplifier 6-SOT-23 -40 to 125 |  |  | Texas Instruments | INA181A1IDBVR |  |  | H1.45mm | INA181A1IDBVR
2 | 16MHz | RESONADOR_CERAMICO-UNKN1 | CSTNE16M0V530000R0 | Y1, Y2 |  |  |  | Murata Electronics | CSTNE16M0V530000R0 |  |  | H0.9mm | CRES-3.2x1.3-16MHz

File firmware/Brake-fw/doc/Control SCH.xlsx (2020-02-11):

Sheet: GUIA
 | Cómo utilizar la CONTROL SCH: |  | CHANGELOG
 |  | Valores del check | # | Autor | Fecha | Cambio
1 | La hoja R1 corresponde a la primera revisión. | Y | 1 | Javier Suvires | 2017-09-01 | Creada la plantilla
 |  | N | 2
2 | Se rellena el campo de proyecto, revisión (se coloca el número de revisión) y se añade el nombre de la persona que va a pasar la revisión y la fecha. |  | 3
 |  |  | 4
 |  |  | 5
3 | Se pasa cada item de la lista de revisión y se marca Y o N en check. |  | 6
 |  |  | 7
 |  |  | 8
4 | Tras finalizar la plantilla se indica si la placa es APTA o NO APTA para fabricación. |  | 9
 |  |  | 10
 |  |  | 11
5 | Si se va a pasar una revisión 2 o 3 o X se copiará la hoja R1 y se cambiará a RX y se borran todas las casillas en blanco. |  | 12
 |  |  | 13
 |  |  | 14
 |  |  | 15
 |  |  | 16
 |  |  | 17

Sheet: R1
 |  |  | SCH CONTROL
Proyecto: |  |  |  | APTO O NO APTO
Revisión:
Autor:
Fecha:
Orden | Bloque | Descripción | Especificación | Anomalía | Corrección | Check
1 |  | El esquema contiene el nombre del creador
2 |  | El esquema contiene la fecha de creacion
3 |  | El esquema contiene el listado de bloques usados y la fecha del bloque
4 |  | El esquema contiene el listado de librerias usadas y la fecha de la librería
5
6
7
8
11
12
13
14
15
16
17 | Montaje | El esquema contiene fiduciales
18
19
20
21
22 | COMPONENTES | Todos los componentes estan completamente definidos
23
24
25
26
27 | Visual | Todas las partes del esquemas estan agrupadas y con su nombre
28
29
30
31
32
33
34
35 | BOM | El BOM se genera completo.

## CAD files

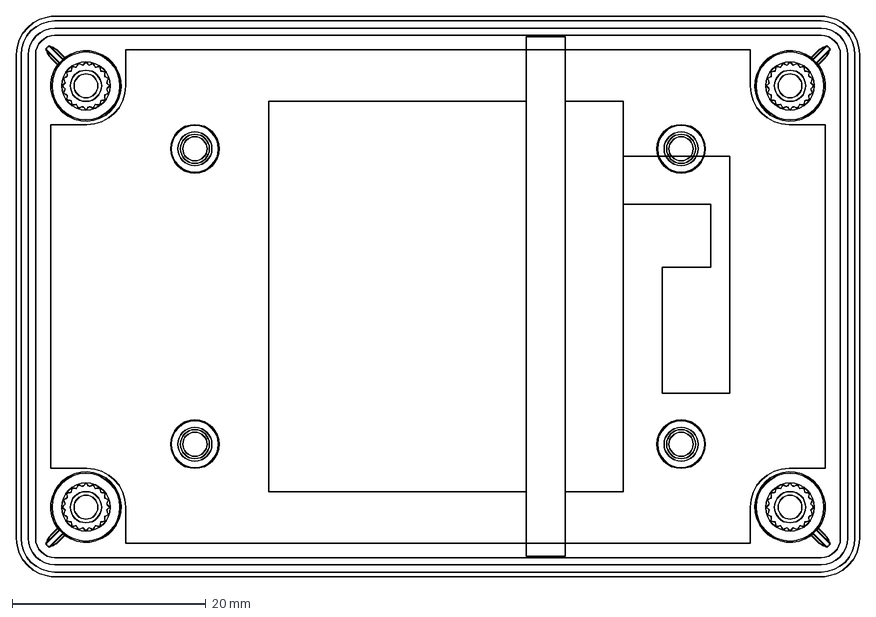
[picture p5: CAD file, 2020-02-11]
hardware/Brake-hw/CAD/PCB-L.dxf
87.1 x 57.9 mm

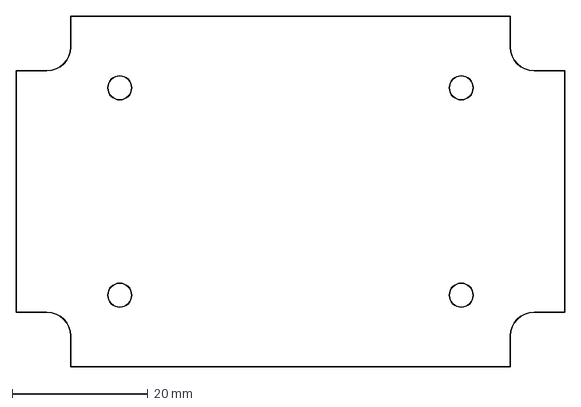
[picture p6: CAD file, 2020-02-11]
hardware/Odometry-hw/CAD/PCB.dxf
80.7 x 51.5 mm

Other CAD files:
hardware/Mechanical Design/1591M.dwg
hardware/Mechanical Design/3Ds/AroCelula.dwg
hardware/Odometry-hw/CAD/Boceto_recover.dwg
hardware/Odometry-hw/CAD/Dibujo.dwg
hardware/Odometry-hw/CAD/Boceto.dwg
hardware/Brake-hw/CAD/Dibujo.dwg
hardware/Brake-hw/CAD/Boceto_recover.dwg
hardware/Brake-hw/CAD/Boceto.dwg

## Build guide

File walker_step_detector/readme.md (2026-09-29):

step detector package

step detector relies on 

active area

leg detection

kalman filtering

Ver `docs/detect_steps_algorithm.md` para una descripción detallada del
algoritmo de `detect_steps` (la variante recomendada) y `eval_results/`
para los datos de validación contra ground truth de mocap.

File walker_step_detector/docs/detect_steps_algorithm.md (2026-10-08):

# `detect_steps` (RF) — descripción del algoritmo

De las tres variantes del paquete (`detect_steps`, `km_detect_steps`,
`detect_steps_s`), `detect_steps` (clasificador Random Forest) es la más
fiable con margen claro — validado sobre 47 bags de
`soma13kp/datasets/labeled_bags` (~14.000 detecciones por lado) contra
ground truth de mocap. Ver `eval_results/` para los datos crudos de cada
corrida. Pipeline completo, de `/scan` a `/detected_step_{left,right}`.

## 1. Segmentación del scan (`laser_processor.cpp`)

Cada punto válido del `LaserScan` (rango dentro de `[range_min, range_max]`)
se convierte a cartesianas y se agrupa por **distancia euclídea entre
puntos consecutivos** angularmente (`splitConnected`, umbral
`cluster_dist_euclid`, 0.13 m por defecto): dos puntos quedan en el mismo
clúster si están a menos de esa distancia. Después se descartan:

- Clústeres con menos de `min_points_per_cluster` puntos (ruido).
- Clústeres a más de `max_detect_distance` del sensor.

## 2. Extracción de características (`cluster_features.cpp`)

Por cada clúster superviviente, 17 características geométricas — el set de
**Arras et al. 2007** ("Using Boosted Features for the Detection of People
in 2D Range Data"), el mismo que usa el `leg_detector` clásico de ROS:

```
num_points, std, avg_median_dev, width, linearity, circularity, radius,
boundary_length, boundary_regularity, mean_curvature, ang_diff, iav,
std_iav, distance, distance/num_points, occluded_right, occluded_left
```

`linearity`/`circularity` salen de un SVD sobre los puntos centrados;
`occluded_left/right` miran si el punto justo antes/después en el barrido
angular está más lejos (indicio de que el clúster sigue detrás de algo).

## 3. Clasificación (Random Forest, OpenCV `cv::ml::RTrees`)

El vector de 17 features se pasa al forest cargado desde
`trained_step_detector_res_0.33.yaml`. `predict()` devuelve exactamente
**±1** (confirmado empíricamente cargando el modelo y probando vectores
sintéticos) — un clasificador binario pierna/no-pierna, no una
probabilidad continua. Se remapea a `confidence = 0.5*(1+predict())` ∈
{0, 1}.

## 4. Filtro de confianza + tope de clusters (`detect_steps.cpp::getCentroids`)

Estaba declarado y logueado pero nunca aplicado (bug encontrado y
arreglado en esta ronda de trabajo). Ahora:

- Se descartan clústeres con `confidence < detection_threshold`.
- Si sobran más de `max_detected_clusters`, se quedan los N más
  confiables (no los N primeros del barrido).

Este fue, de lejos, el fix de mayor impacto medido: en 47 bags, match_rate
subió de ~55-64% a ~90-96%.

## 5. Asociación y seguimiento (`legs_tracker.cpp` + `track_leg.cpp`)

Un `LegsTracker` con dos `TrackLeg` internas (una por pierna, no
etiquetadas a priori como izq/der). Cada `TrackLeg` lleva un EKF
**independiente** con un modelo oscilatorio periódico por eje:
`pos = d + a·sin(w·t + p)` (`d`=offset, `a`=amplitud, `f`→`w`=frecuencia,
`p`=fase) — modela el vaivén de la marcha, no una posición estática. Las
dos piernas no comparten estado ni se restringen mutuamente en el filtro;
toda la coordinación entre ellas vive en la capa de asociación, no en el
EKF.

Por cada frame de detecciones, en orden de prioridad:

**a) Ambas pistas con estimación propia** → emparejamiento exclusivo: de
todas las parejas posibles de candidatos, se escoge la que minimiza
`dist(cand_i, ref_izq) + dist(cand_j, ref_der)` — cada pierna se queda con
una candidata distinta (evita que las dos compitan por la misma y una se
quede sin nada). Si la mejor pareja y la contraria (izq↔der intercambiadas)
quedan casi empatadas en coste (margen 8 cm), se desempata por
**alternancia de marcha**: en cada instante una pierna va más rápido
(swing) que la otra (stance), así que se prefiere la asignación que
mantenga ese orden de velocidades en vez de invertirlo de golpe — justo el
caso de piernas cruzándose, donde la posición sola es ambigua.

**b) Solo una pista con estimación** (la otra acaba de perderla o nunca la
tuvo) → la establecida reclama su candidata más cercana primero; el resto
se reparte por la heurística espacial (única pista disponible para una
pierna sin referencia).

**c) Ninguna con estimación** (arranque) → heurística espacial pura
(`y>0` → izquierda).

Dentro de cada `TrackLeg`, `predict_step()` aplica un **gate de distancia**
(`max_association_dist`, 0.5 m): la candidata más cercana solo se acepta
como medida si está por debajo del gate; si no, el EKF solo predice (no
actualiza) — evita engancharse a un clúster espurio cuando la detección
real falta ese frame.

**Recuperación de pista perdida**: si pasan `max_track_loss_frames` (15)
ciclos seguidos sin una medida aceptada, la pista suelta su bloqueo y
vuelve a competir por cualquier candidata disponible, en vez de seguir
comparando contra una referencia que ya no significa nada. Al soltar el
bloqueo también se vacía el buffer de calentamiento de fase/amplitud (ver
punto 8 más abajo) y se desmarca `phase_warmed_`: el próximo enganche
recalcula amplitud y fase desde cero en vez de arrastrar las de antes de
perder la pista (que ya no tienen por qué ser válidas). Verificado
disparando el mecanismo a propósito (gate artificialmente estricto sobre
un bag real): la pista pierde el bloqueo, reengancha con la heurística de
`LegsTracker`, acumula medidas nuevas y recalcula amplitud/fase -- ver
"Verificación del reenganche" más abajo.

**Re-etiquetado izquierda/derecha**: la decisión de qué pista interna es
"izquierda" no se toma con el signo de `y` de la primerísima detección
(ruidoso) — se pospone hasta que cada pista acumula ≥5 medidas reales, y
entonces se decide una vez por la `y` media de cada una.

## 6. Publicación

`get_steps()` devuelve el estado predicho de cada pista (posición,
velocidad, confianza) etiquetado según la decisión de re-etiquetado; se
publica en `/detected_step_{left,right}` solo si el `frame_id` no es
`"invalid"`.

## Rendimiento validado

47 bags, ~14.000 detecciones/lado: match_rate **~95.7-95.9%** (tras el
calentamiento de fase/amplitud del EKF, ver "Investigación del swap_rate
residual" más abajo, punto 8 -- antes ~93.7-93.8%), error medio de posición
~10 cm, swap_rate ~9.3% por cada 100 pares consecutivos. La
fusión con las otras dos variantes (`detect_steps_fused`) no la mejora —
verificado con tres métodos distintos (fusión ingenua, fusión con
prioridad RF, y análisis quirúrgico aislando solo los ciclos donde el
respaldo se activa). Ver `eval_results/` para los JSON de cada corrida.

## Investigación del swap_rate residual (~10%)

Se investigó qué dispara los swaps de `rf` (el cambio de identidad
izquierda/derecha entre dos detecciones consecutivas), en orden:

1. **¿Cruce físico de piernas?** No. En 47 bags, el 99.8% de los swaps
   ocurren con las piernas claramente separadas (20-45 cm), no cruzadas ni
   juntas (`scripts/investigate_swaps.py`).
2. **¿EKF acoplado modelando la relación mecánica entre piernas (fase
   antifase, ancho de zancada)?** Descartado antes de implementarlo: la
   velocidad de las dos piernas está débilmente **correlacionada
   positivamente** (no antifase) en 37/47 bags, y el ancho de zancada no
   es lo bastante estable como para servir de restricción fuerte
   (`scripts/validate_leg_coupling.py`).
3. **¿Deriva de la predicción interna del EKF?** Sí, mayoritariamente: en
   el 64.3% de los swaps, la referencia interna (`l_ref`/`r_ref`, antes de
   decidir la asociación de ese ciclo) ya apuntaba hacia el tobillo
   equivocado (`scripts/investigate_ref_drift.py`). El otro 35.7% ocurre
   con la referencia todavía correcta -- probablemente un efecto emergente
   del emparejamiento exclusivo (minimiza el coste conjunto de las dos
   piernas, así que la deriva de la OTRA pista puede "robarle" una pierna
   a esta aunque su propia referencia sea buena).
4. **¿Ajustar Q/R (ruido de proceso/medida) del EKF?** Empeora, no mejora
   -- ver el comentario en `TrackLeg::init()` (`src/track_leg.cpp`) y
   `eval_results/result_2026-09-28_baseline_isolated.json` vs
   `result_2026-09-28_qr_tuned_isolated.json`. La causa de la deriva no es
   un Q/R mal calibrado en sí, sino que el modelo de amplitud/frecuencia
   es casi inobservable desde la inicialización casi nula (`a0=f0=p0=0.001`)
   -- arreglarlo necesitaría repensar la inicialización o la
   parametrización del modelo, no solo sus matrices de ruido.
5. **¿Reinicializar `a0`/`f0` a valores reales en vez de ~0?** También
   empeora. Se midió `a0=0.15m`, `f0=0.6Hz` (medianas de amplitud/frecuencia
   real de tobillo, 47 bags, `scripts/estimate_gait_params.py`) contra el
   mismo baseline aislado -- `eval_results/result_2026-09-28_gait_init_isolated.json`:
   match_rate de rf cae de 93.7/93.8% a 88.9/86.7%, con mean_err/swap_rate
   casi iguales. Motivo probable: `p0` se dejó en 0.001 (fase arbitraria) --
   con amplitud/frecuencia ya realistas, el término periódico SÍ oscila
   desde el primer instante, pero con la fase equivocada (no hay forma de
   saber la fase real de la zancada al arrancar una pista), inyectando un
   error de predicción que antes no existía (con `a0~0` el modelo era casi
   estático, sin oscilación que pudiera desfasarse). Revertido. Ver el
   comentario en `launch/test_step_detector_variants.launch.py`.

6. **¿Referencia de asociación/gating por última medida real en vez de la
   predicción del EKF?** Primer resultado positivo (aunque modesto):
   `LegsTracker::add_detections()` (coste de emparejamiento exclusivo) y
   `TrackLeg::predict_step()` (gate de aceptación) usaban `get_step()`
   (`curr_step`, la predicción del modelo periódico -- justo lo que deriva)
   como referencia. Se cambió a `TrackLeg::assoc_ref()`, que devuelve la
   última medida real ACEPTADA por el gate (cruda, sin pasar por el EKF),
   sin tocar el filtro ni sus parámetros en absoluto. Medido en 47 bags
   (aislado) -- `eval_results/result_2026-09-28_baseline_isolated.json` vs
   `result_2026-09-29_assoc_ref_deadreckon_isolated.json`:

   | | match_rate | mean_err | swap_rate/100 |
   |---|---|---|---|
   | rf/left | 93.68%→**94.47%** | 0.100→0.105 m | 10.06→9.99 |
   | rf/right | 93.81%→**94.87%** | 0.099→0.099 m | 9.45→**8.84** |
   | km/left | 81.60%→82.38% | 0.139→0.141 m | 14.95→14.21 |
   | km/right | 80.65%→80.84% | 0.154→0.157 m | 15.68→15.24 |
   | seg | ~sin cambio | ~sin cambio | ~sin cambio |
   | fused/left | 94.13%→93.77% | 0.102→0.107 m | 11.15→11.01 |
   | fused/right | 96.01%→**93.42%** | 0.101→0.104 m | 10.50→9.86 |

   `rf` mejora en las tres métricas a la vez (primera vez en esta
   investigación), superando el 94% de match_rate en ambos lados. `km`
   también mejora ligeramente. `fused` **empeora** (especialmente el lado
   derecho, -2.6 puntos) -- probablemente porque sus candidatos mezclan
   detecciones de calidad dispar (rf/km/seg con fallback), y una medida
   aceptada ruidosa ahora se propaga sin amortiguar a la referencia del
   siguiente ciclo (antes, el blend del EKF -- ganancia de Kalman <1 --
   suavizaba ese ruido de un solo frame). Como ya se sabía que `fused` no
   aporta nada sobre `rf` solo, esta regresión no cambia la recomendación
   de usar `rf`. Cambio conservado (mejora neta para `rf`, que es la
   variante en uso). Ver `include/walker_step_detector/track_leg.h`.

7. **¿Extender #6 extrapolando `assoc_ref()` con velocidad** (en vez de
   solo la última posición)? Empeora, y con claridad -- peor incluso que no
   tocar nada. Se añadió `accepted_speed_` (velocidad entre las dos últimas
   medidas ACEPTADAS, no las últimas añadidas) y se extrapoló la referencia
   hacia el instante `ti` actual antes de buscar la candidata más cercana.
   Medido en 47 bags (aislado) -- `result_2026-09-28_baseline_isolated.json`
   vs `result_2026-09-29_assoc_ref_velocity_isolated.json`: rf match_rate
   94.47/94.87% (#6) → **89.4/88.9%** (peor que el 93.68/93.81% original,
   sin ningún fix). Motivo: diferenciar posiciones consecutivas para
   obtener una velocidad amplifica el ruido de medida (más cuanto más corto
   el intervalo entre medidas, típicamente 0.03-0.2s aquí), y extrapolar la
   referencia con esa velocidad ya ruidosa reintroduce más error del que
   `assoc_ref()` sin extrapolar evitaba. Revertido -- el código de
   `accepted_speed_`/`assoc_ref(double ti)` se quitó del todo, no se dejó
   detrás de un flag; ver el comentario en `track_leg.h::assoc_ref()`.

8. **¿Calentamiento de fase/amplitud por mínimos cuadrados tras acumular
   medidas reales?** Mejor resultado de toda esta investigación. La pista
   arranca igual que siempre (`a0=f0=p0=0.001`, casi estática -- el
   comportamiento ya conocido y bueno mientras hay pocos datos). En cuanto
   acumula `WARMUP_WINDOW=12` medidas reales ACEPTADAS (buffer propio,
   `warmup_ti_`/`warmup_x_`/`warmup_y_`), resuelve por mínimos cuadrados
   (sistema 2x2, sin Eigen) la amplitud y fase de cada eje que mejor
   explican esas 12 medidas, con la frecuencia FIJA en 0.6Hz (la mediana
   real medida sobre mocap, `scripts/estimate_gait_params.py` -- fijarla
   sola como `f0` ya se había probado y empeorado, punto 5; aquí solo sirve
   de ancla para resolver amplitud/fase, no se usa como parámetro fijo del
   modelo) y reinyecta esos tres valores en el EKF (`ekf.init()`, que solo
   pisa el estado `x`, no la covarianza) dejando `d_x`/`d_y` intactos (ya
   bien seguidos por la ganancia por defecto). Se repite cada vez que la
   pista pierde el bloqueo y reengancha (`register_miss()` vacía el buffer
   y desmarca `phase_warmed_`), no solo una vez al arrancar el nodo. Ver
   `TrackLeg::warmup_reseed()` en `track_leg.cpp`.

   Medido en 47 bags (aislado) -- `result_2026-09-28_baseline_isolated.json`
   (sin ningún fix) vs `result_2026-09-29_assoc_ref_deadreckon_isolated.json`
   (#6 solo) vs `result_2026-09-29_warmup_phase_isolated.json` (#6 + #8):

   | | sin fix | #6 (assoc_ref) | #6+#8 (+ calentamiento) |
   |---|---|---|---|
   | rf/left match | 93.68% | 94.47% | **95.94%** |
   | rf/right match | 93.81% | 94.87% | **95.72%** |
   | rf/left mean_err | 0.100 m | 0.105 m | **0.099 m** |
   | rf/right mean_err | 0.099 m | 0.099 m | 0.099 m |
   | rf/left swap/100 | 10.06 | 9.99 | **9.30** |
   | rf/right swap/100 | 9.45 | 8.84 | 9.27 |
   | fused/left match | 94.13% | 93.77% (empeoraba) | **95.91%** |
   | fused/right match | 96.01% | 93.42% (empeoraba) | 94.56% (recupera casi todo) |

   `rf` mejora ~2.1-2.3 puntos de match_rate sobre el baseline sin tocar
   nada (el mayor salto medido en toda la investigación), con mean_err
   igual o mejor y swap_rate mejor en ambos lados. Además **recupera casi
   toda la regresión de `fused`** que había introducido #6 solo (94.13/96.01%
   → 93.77/93.42% con #6 → 95.91/94.56% con #6+#8) -- consistente con que
   la causa de esa regresión (medidas ruidosas de km/seg propagándose sin
   amortiguar) se mitiga si el propio modelo periódico ya converge antes a
   parámetros realistas, en vez de necesitar más ciclos con `a~0`. `km`/`seg`
   quedan prácticamente sin cambios (esperable: kalman_enabled=false en la
   configuración de esta evaluación para esas dos variantes, ver
   `launch/test_step_detector_variants.launch.py` -- no pasan por `predict_step()`).

9. **¿Extender #8 estimando también la frecuencia por eje** (búsqueda en
   rejilla 0.2-1.2Hz, paso 0.02Hz, sobre el mismo ajuste 2x2, en vez de
   fijarla a 0.6Hz)? Empeora con claridad, y por debajo incluso del
   baseline sin ningún fix en el lado derecho. Medido en 47 bags (aislado)
   -- `result_2026-09-29_warmup_phase_isolated.json` (#8, f fija) vs
   `result_2026-09-29_warmup_freq_grid_isolated.json` (#8 + rejilla de f):

   | | sin fix | #8 (f fija 0.6Hz) | #8 + rejilla de f |
   |---|---|---|---|
   | rf/left match | 93.68% | **95.94%** | 95.61% |
   | rf/right match | 93.81% | **95.72%** | **92.43%** (peor que sin fix) |
   | rf/left mean_err | 0.100 m | **0.099 m** | 0.105 m |
   | rf/right mean_err | 0.099 m | **0.099 m** | 0.104 m |
   | fused/right match | 96.01% | 94.56% | **92.70%** (peor que sin fix) |

   Motivo probable: con solo `WARMUP_WINDOW=12` medidas (~1-2 ciclos de
   marcha), dejar la frecuencia libre añade un grado de libertad que
   sobreajusta al ruido de ESA ventana concreta -- la rejilla encuentra la
   frecuencia que mejor explica esas 12 medidas ruidosas, no
   necesariamente la frecuencia real de la marcha. La mediana fija de 47
   bags de mocap (0.6Hz) generaliza mucho mejor que una estimación de
   ventana corta. Revertido -- el código de la rejilla se quitó del todo
   (no se dejó detrás de un flag), igual que en el punto 7. Ver el
   comentario en `track_leg.h::WARMUP_FREQ_HZ`.

**Estado**: causa identificada (deriva de predicción, mayoritariamente) y
con un fix real y validado (#8, sobre #6): rf sube de 93.7/93.8% a
95.9/95.7% de match_rate, con mean_err y swap_rate iguales o mejores en
las dos métricas. Su extensión obvia (#9, estimar también la frecuencia)
empeora, igual que la de #6 (#7, extrapolar con velocidad) -- las dos
extensiones fallaron por el mismo patrón: introducir una estimación
adicional a partir de pocas medidas ruidosas (velocidad por diferenciación
en #7, frecuencia por ventana corta en #9) resulta peor que quedarse con
la cantidad mínima de información que ya funcionaba. No cierra el
swap_rate del todo (sigue en ~9.3 por cada 100 pares). El estado final
vigente es #6+#8 (`assoc_ref()` sin extrapolar + calentamiento de
amplitud/fase con frecuencia fija). Si se quiere seguir apurando, la vía
que queda sin probar es más estructural: sustituir el modelo periódico por
uno de velocidad constante -- aunque cada vez parece menos necesario, dado
que el modelo periódico, bien inicializado, SÍ está aportando valor medible
y las dos ampliaciones "fáciles" (velocidad, frecuencia) ya se han agotado
sin éxito. Cualquier intento futuro de EKF debe medirse con
`scripts/run_multibag_eval.py` en un `ROS_DOMAIN_ID` propio -- un proceso
ROS ajeno compartiendo el dominio por defecto contaminó una medida anterior
y produjo una conclusión falsa ("catastrófico") que tuvo que corregirse.

## Lanzadores y cómo evaluarlos

- **`launch/step_detector.launch.py`** -- el del robot real. Solo lanza
  `detect_steps` (RF), con los parámetros validados, leyendo `/scan_filtered`
  y publicando `/detected_step_left` y `/detected_step_right`. No lanza el
  filtro láser: `/scan_filtered` lo genera `walker_bringup
  laser_filter.launch.py` en el robot.
- **`launch/test_step_detector.launch.py`** -- el mismo launcher del robot,
  sin robot: incluye `walker_bringup/launch/test/unified_bag_replay.launch.py`
  (reproduce `/scan`, `/tf`, `/tf_static` del bag y lanza el TF del andador),
  `laser_filter.launch.py` (genera `/scan_filtered` como el robot) y
  `step_detector.launch.py` sin tocar. `step_detector` solo se suscribe a
  `/scan_filtered`, así que no hacen falta handles ni configuración de
  usuario. Argumentos: `bag_path`, `rate`, `topics` (por defecto `/scan /tf
  /tf_static`), `publish_walker_tf`, `replay_delay` (espera antes de
  reproducir, por defecto 3 s, para que el detector ya esté suscrito).
- **`launch/test_step_detector_variants.launch.py`** -- el de antes (se
  llamaba `test_step_detector.launch.py`): las cuatro variantes juntas
  (rf/km/seg/fused) sobre el mismo bag. Es el que usaron todas las
  evaluaciones de `eval_results/` anteriores a 2026-10.

Evaluar contra mocap con el launcher nuevo (hay que reproducir también el
ground truth, que no está en el `topics` por defecto; elige un
`--domain-id` que nadie más use):

```bash
python3 scripts/run_multibag_eval.py --bags-dir $DATASETS/labeled_bags \
    --out-dir /tmp/eval --rate 4.0 --domain-id <libre> \
    --launch-file test_step_detector.launch.py \
    --launch-args "topics:='/scan /tf /tf_static /labeled_markers /rigid_bodies'" \
    --detected-topics "/detected_step_left /detected_step_right" \
    --replay-delay 8 --out result.json
```

El grabador solo recibe el ground truth una vez que el reproductor empieza
a publicarlo, así que ninguno de los dos flujos evalúa el bag entero.
Medido en `CA_test01` (89 s de bag, rate 4): el launcher de variantes
(arranca el bag a la vez que el launch y el grabador se suscribe unos 5 s
después) se pierde los primeros **14.7 s** (cubre el 83%); el launcher nuevo
con `--replay-delay 8` se pierde **7.4 s** (cubre el 92%), es decir ~1.9 s
de reloj de pared hasta que el grabador engancha el ground truth, que a rate
4 son 7.4 s de bag (a rate 1 serían ~1.9 s). Las cifras históricas de
`eval_results/` excluyen ese tramo inicial, y por eso no son estrictamente
comparables con las del launcher nuevo, que cubre algo más.

## Verificación del reenganche tras perder la pista

Pregunta directa: con el estado actual del código (#6+#8), ¿es capaz una
pista de recuperarse si pierde la medida? El mecanismo de recuperación en
sí (`register_miss()`/`max_track_loss_frames`, descrito en el punto 5) no
se ha tocado en esta ronda -- solo se le añadió, sobre ese mecanismo ya
existente, que el reenganche también dispare un recalentamiento de
fase/amplitud nuevo (punto 8).

Comprobado en vivo, no solo leyendo el código:

- **Con el gate real (`max_association_dist=0.5m`)**: en 4 bags distintos
  (`MT_test18`, `CA_test06`, `MF_test19`, `MT_test17`, logs `RCLCPP_DEBUG`
  activados vía `publish_clusters=true`), **0 pérdidas de pista completas**
  en ninguno -- solo los 2 calentamientos iniciales (uno por pierna, al
  arrancar). Coherente con el diagnóstico de los puntos 1-3 arriba: el
  ~9% de swap_rate residual de `rf` viene de **asignar mal la detección
  mientras la pista sigue "enganchada"** (deriva de referencia en el
  emparejamiento exclusivo), no de perder la pista del todo. Con el gate
  real, `consecutive_misses_` rara vez llega a los 15 seguidos.
- **Con el gate forzado a 0.04m** (artificialmente estricto, solo para
  forzar el mecanismo, no un valor propuesto para producción) sobre
  `CA_test01`: 16 pérdidas de pista y 6 recalentamientos completos.
  Secuencia real del log:
  ```
  t=118.79  (right) sin medida aceptada en 15 ciclos. Soltando bloqueo.
  t=122.37  (right) warmup_reseed: a=(0.012,0.007) p=(1.540,-0.774) f=0.60Hz
  ```
  La pista derecha suelta el bloqueo, `LegsTracker` la deja competir de
  nuevo por cualquier candidata (rama "una pista sin estimación" del punto
  5), acumula `WARMUP_WINDOW=12` medidas nuevas sin otra pérdida de por
  medio, y recalcula amplitud/fase desde cero -- exactamente el
  comportamiento esperado.

**Conclusión**: sí, reengancha. El mecanismo de recuperación es el mismo
de antes de esta ronda de trabajo (no introduce ni arregla nada ahí); lo
nuevo es que el reenganche ya no hereda una fase potencialmente obsoleta.

## Filtro de confianza en `km_detect_steps` y bug crítico de inicialización del EKF

Origen: otra sesión ([mocap-walker][validación], ver `walker_mocap_eval/readme.md`)
encontró que en `CA_test09`, una sola sesión produce valores de longitud de
zancada del andador real disparatados (`left_sdl`=87m, `right_spl`=39m,
`right_sdl`=76m) que contaminan permanentemente la media de
`gait_monitor_speed` (y también `/support_centroid` de
`walker_centroid_support`) el resto del test, porque ninguno de los dos
rechaza outliers al promediar sobre toda la sesión. Hipótesis propuesta:
`km_detect_steps.cpp::getCentroids()` fuerza siempre exactamente 2 clusters
de k-means sobre `/scan_feet`, sin ningún filtro de confianza (a diferencia
de `detect_steps`/RF, que sí descarta clusters con pocos puntos) -- una
detección espuria puntual se coló como si fuera un pie real.

**Filtro de confianza implementado** (el fix propuesto, y sigue siendo
correcto tenerlo): `find_centroid()` ahora también devuelve `used_points`
(cuántos puntos reales, tras el filtro de `max_d`, contribuyeron al
centroide -- antes se calculaba y se descartaba). `getCentroids()` no
publica un `StepStamped` para un cluster con `used_points <
min_points_per_cluster` (nuevo parámetro, default 3, mismo nombre/valor que
ya usaba RF) -- en vez de forzar siempre 2 candidatas, ahora puede devolver
0, 1 o 2 según la calidad real de los datos, igual que RF; `LegsTracker` ya
sabía manejar cualquiera de esos casos.

**Pero el filtro de confianza NO era la causa del outlier de `CA_test09`**:
comprobado directamente reproduciendo `km_detect_steps` solo contra ese bag
-- con `kalman_enabled=false` (paso a través crudo, sin EKF) la salida está
acotada a ~1m con o sin el filtro (0 rechazos: los clusters crudos ya eran
razonables). Con `kalman_enabled=true` (la configuración real que usaba
`replay_offline.launch.py` antes de cambiar a RF) **la pista derecha salta
a y=407m en su SEGUNDA medida**, con una entrada perfectamente normal --
el problema está en el EKF, no en el clustering.

**Causa real encontrada**: `TrackLeg::t` (miembro, "instante de la última
predicción") se inicializa a `0` en `init()` como valor centinela de
"todavía no se ha predicho nunca" -- pero `predict_step()` lo usaba tal
cual para calcular `u.dt() = (ti - t) * 1e-9` en la primerísima llamada,
dando un `dt` de **~1.79e9 segundos** (el tiempo transcurrido desde el
epoch Unix), no un intervalo real entre frames. Ese `dt` gigante entra en
el jacobiano de `SystemModelLeg.hpp` (`F(PX,FX) = 2*pi*dt`) y dispara una
covarianza del EKF descontrolada desde el primer ciclo -- la siguiente
actualización con una medida real, con esa covarianza ya disparada, es lo
que produce el salto a cientos de metros. Afecta por igual a `rf`/`km`/`seg`
(mismo `TrackLeg` compartido): `rf` y `seg` no lo mostraban en este bag por
pura suerte de *timing* (su primera medida aceptada no caía justo en el
ciclo con la covarianza recién disparada, ver el punto 5 sobre `tracked=false`
en los primeros frames), no porque no les afectase.

**Fix**: en `predict_step()`, si `t==0` (nunca predicho), se fija `t=ti`
antes de calcular `u.dt()` -- la primerísima predicción usa `dt=0` en vez
de "tiempo desde el epoch". Confirmado en vivo: `CA_test09` con
`kalman_enabled=true` pasa de y=407m a un máximo de ~1m, con o sin el
filtro de confianza. Validado además en 47 bags completos (aislado) --
`eval_results/result_2026-09-30_km_confidence_and_t0fix_isolated.json` vs
`result_2026-09-29_warmup_phase_isolated.json`: cambios pequeños y dentro
del ruido normal de una corrida a otra en match_rate/mean_err/swap_rate de
las cuatro variantes (ninguna regresión relevante) -- esperable, ya que
esta métrica agregada nunca fue sensible a este bug (mide posición
frame a frame contra mocap con gate, no promedios de sesión completa como
`gait_monitor_speed`/`walker_centroid_support`, que es donde el bug se
manifestaba). Ver `TrackLeg::predict_step()` en `track_leg.cpp`.

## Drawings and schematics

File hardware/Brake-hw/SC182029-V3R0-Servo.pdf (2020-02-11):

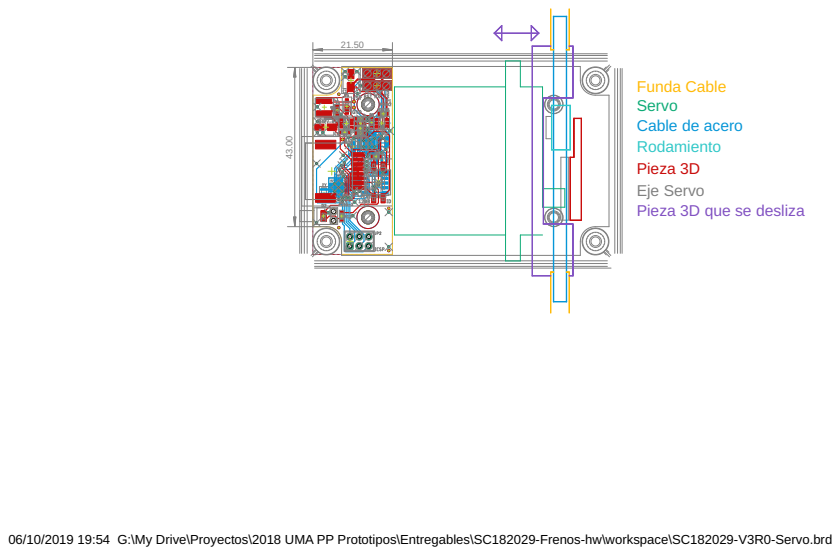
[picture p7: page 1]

Funda Cable
Servo
Cable de acero
Rodamiento
Pieza 3D
Eje Servo
Pieza 3D que se desliza

06/10/2019 19:54 G:\My Drive\Proyectos\2018 UMA PP Prototipos\Entregables\SC182029-Frenos-hw\workspace\SC182029-V3R0-Servo.brd

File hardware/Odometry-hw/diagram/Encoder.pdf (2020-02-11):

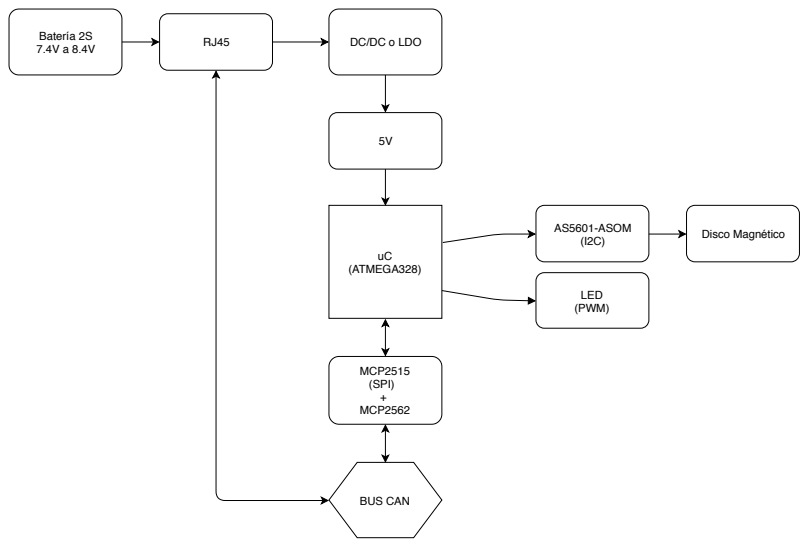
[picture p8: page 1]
uC (ATMEGA328); BUS CAN; AS5601-ASOM (I2C); LED (PWM); Disco Magnético; MCP2515 (SPI) + MCP2562

DC/DC o LDO Batería 2S

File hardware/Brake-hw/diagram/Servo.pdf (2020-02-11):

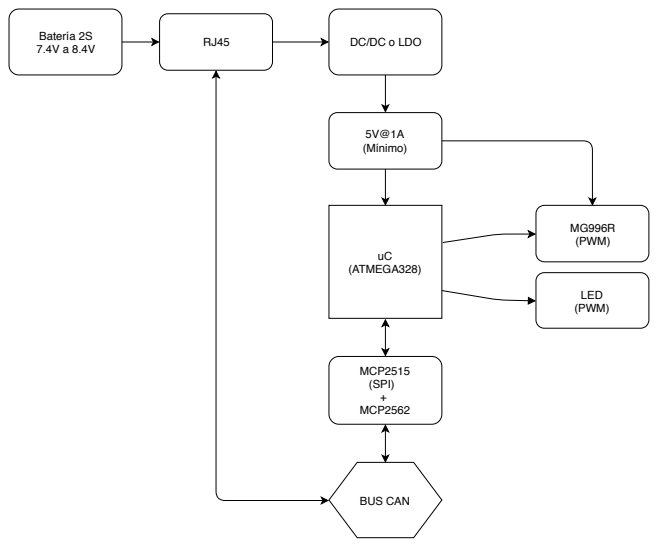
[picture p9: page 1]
uC (ATMEGA328); BUS CAN; MG996R (PWM); 5V@1A (Mínimo); LED (PWM); MCP2515 (SPI) + MCP2562

DC/DC o LDO Batería 2S

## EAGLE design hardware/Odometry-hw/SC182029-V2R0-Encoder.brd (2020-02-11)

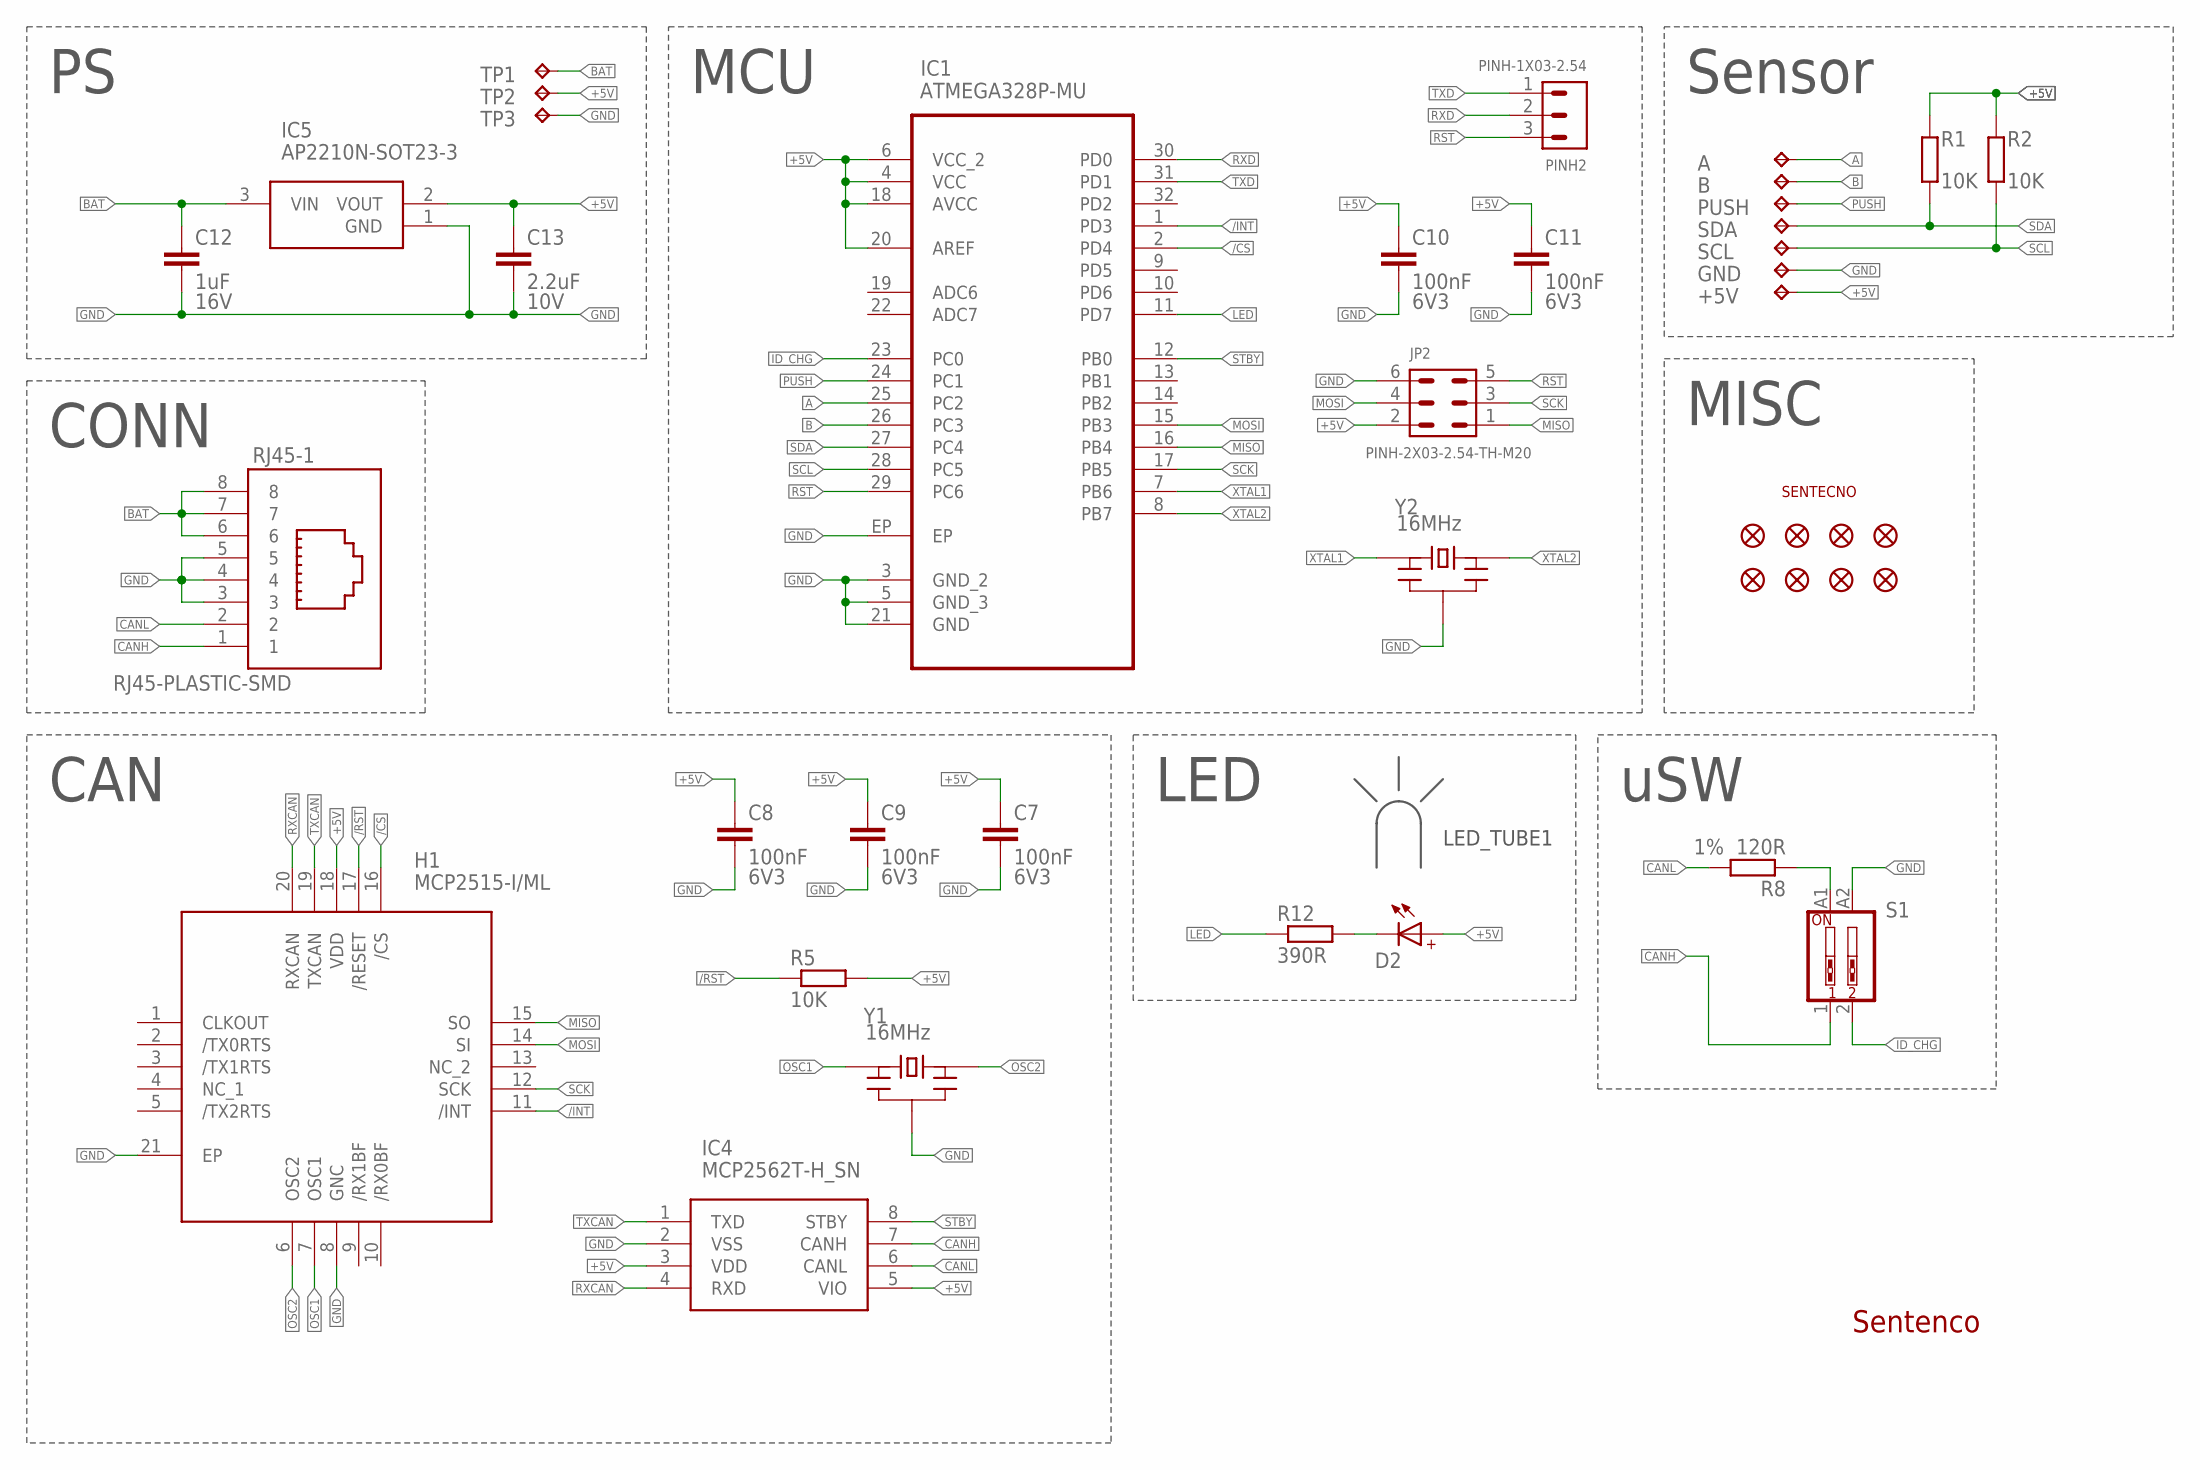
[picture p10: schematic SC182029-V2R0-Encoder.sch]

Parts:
+5V: TPTP20SQ; TP20SQ
A: TPTP20SQ; TP20SQ
B: TPTP20SQ; TP20SQ
C7, C8, C9, C10, C11: 100nF; C0603R
C12: 1uF; C0603R
C13: 2.2uF; C0603R
D2: WL-SMCW-150060BS75000; WL-SMCW_0603
FID1, FID2, FID3, FID4, FID5, FID6, FID7, FID8: FIDUCIALUFIDUCIAL; MICRO-FIDUCIAL
GND: TPTP20SQ; TP20SQ
H1: MCP2515-I/ML; QFN50P400X400X90-21N
IC1: ATMEGA328P-MU; QFN50P500X500X100-33N
IC4: MCP2562T-H_SN; SOIC127P600X175-8N
IC5: AP2210N-SOT23-3; SOT95P280X130-3N
JP2: PINH-2X03-2.54-TH-M20; HDRV6W64P254_2X3_762X508X868P
LED_TUBE1: LED_TUBEH1; LED_TUBE_2
LOGO1: LOGO_SENTECNOLOGO_6X4MM; LOGO_6X4MM
PINH2: PINH-1X03-2.54; PINH-1X03-2.54-1
PUSH: TPTP20SQ; TP20SQ
R1, R2, R5: 10K; R0603R
R8: 120R; R0603R
R12: 390R; R0603R
RJ45-1: RJ45-PLASTIC-SMD; 73304111LF
S1: DIP-SW-2; SMD-DIP-SWITCH-2P
SCL: TPTP20SQ; TP20SQ
SDA: TPTP20SQ; TP20SQ
TP1, TP2, TP3: TPTP08R; TP0.8MMR
Y1, Y2: 16MHz; CSTNE16M0V530000R0

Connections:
+5V: +5V.TP, C7.1, C8.1, C9.1, C10.1, C11.1, C13.1, D2.2 (+), H1.18 (VDD), IC1.4 (VCC), IC1.6 (VCC_2), IC1.18 (AVCC), IC1.20 (AREF), IC4.3 (VDD), IC4.5 (VIO), IC5.2 (VOUT), JP2.2, R1.2, R2.2, R5.2, TP2.TP
/CS: H1.16 (/CS), IC1.2 (PD4)
/INT: H1.11 (/INT), IC1.1 (PD3)
/RST: H1.17 (/RESET), R5.1
A: A.TP, IC1.25 (PC2)
B: B.TP, IC1.26 (PC3)
BAT: C12.1, IC5.3 (VIN), RJ45-1.6, RJ45-1.7, RJ45-1.8, TP1.TP
CANH: IC4.7 (CANH), RJ45-1.1, S1.1
CANL: IC4.6 (CANL), R8.2, RJ45-1.2
GND: C7.2, C8.2, C9.2, C10.2, C11.2, C12.2, C13.2, GND.TP, H1.8 (GNC), H1.21 (EP), IC1.3 (GND_2), IC1.5 (GND_3), IC1.21 (GND), IC1.EP, IC4.2 (VSS), IC5.1 (GND), JP2.6, RJ45-1.3, RJ45-1.4, RJ45-1.5, S1.A2, TP3.TP, Y1.2 (GND), Y2.2 (GND)
ID_CHG: IC1.23 (PC0), S1.2
LED: IC1.11 (PD7), R12.1
MISO: H1.15 (SO), IC1.16 (PB4), JP2.1
MOSI: H1.14 (SI), IC1.15 (PB3), JP2.4
unnamed: R8.1, S1.A1
unnamed: D2.1 (-), R12.2
OSC1: H1.7 (OSC1), Y1.3 (OUT)
OSC2: H1.6 (OSC2), Y1.1 (IN)
PUSH: IC1.24 (PC1), PUSH.TP
RST: IC1.29 (PC6), JP2.5, PINH2.3
RXCAN: H1.20 (RXCAN), IC4.4 (RXD)
RXD: IC1.30 (PD0), PINH2.2
SCK: H1.12 (SCK), IC1.17 (PB5), JP2.3
SCL: IC1.28 (PC5), R2.1, SCL.TP
SDA: IC1.27 (PC4), R1.1, SDA.TP
STBY: IC1.12 (PB0), IC4.8 (STBY)
TXCAN: H1.19 (TXCAN), IC4.1 (TXD)
TXD: IC1.31 (PD1), PINH2.1
XTAL1: IC1.7 (PB6), Y2.3 (OUT)
XTAL2: IC1.8 (PB7), Y2.1 (IN)

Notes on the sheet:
LED
MCU
CAN
CONN
MISC
Sensor
uSW
Sentenco

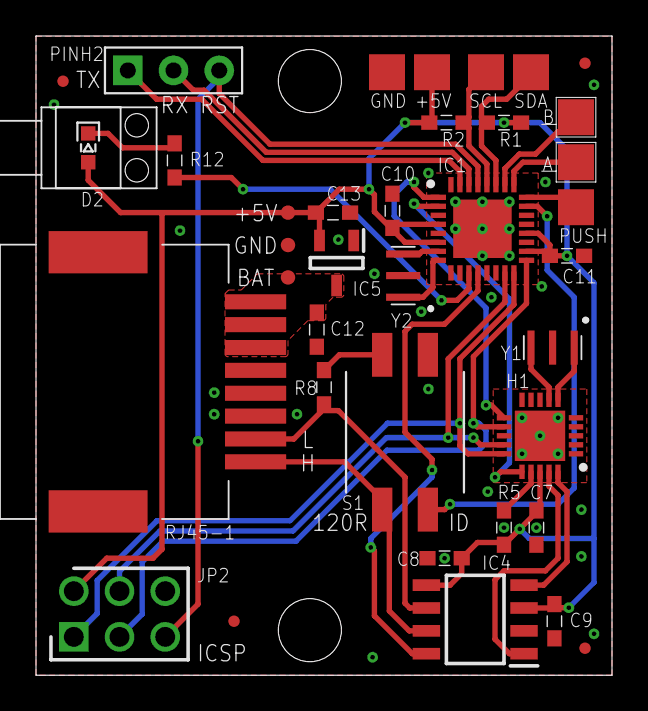
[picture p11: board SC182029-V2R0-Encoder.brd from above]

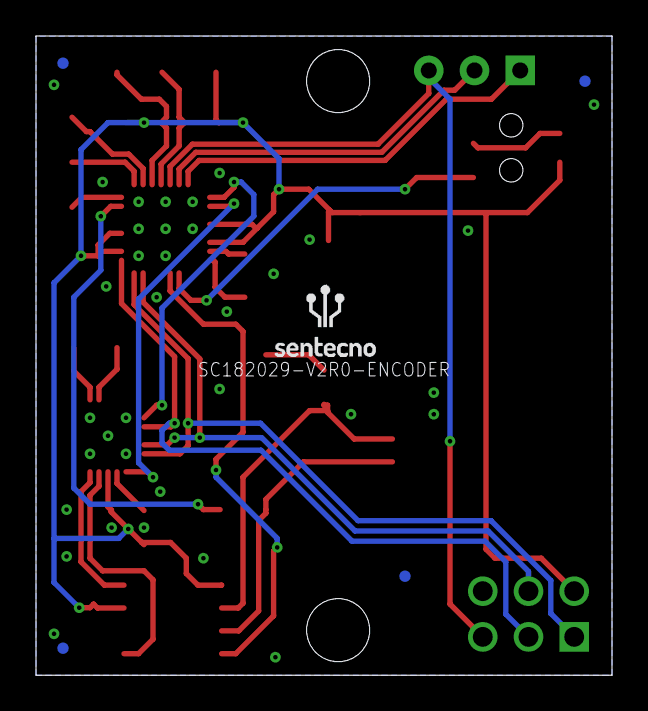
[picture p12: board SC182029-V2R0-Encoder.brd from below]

Board: 2 copper layers, 32.0 x 35.5 mm, 43 parts (5 on the bottom side), 30 nets.

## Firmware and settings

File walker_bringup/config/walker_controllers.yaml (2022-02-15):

controller_manager:
  ros__parameters:
    update_rate: 10  # Hz

    joint_state_broadcaster:
      type: joint_state_broadcaster/JointStateBroadcaster

    diffbot_base_controller:
      type: diff_drive_controller/DiffDriveController

diffbot_base_controller:
  ros__parameters:
    left_wheel_names: ["left_wheel_joint"]
    right_wheel_names: ["right_wheel_joint"]

    wheel_separation: 0.10
    #wheels_per_side: 1  # actually 2, but both are controlled by 1 signal
    wheel_radius: 0.015

    wheel_separation_multiplier: 1.0
    left_wheel_radius_multiplier: 1.0
    right_wheel_radius_multiplier: 1.0

    publish_rate: 50.0
    odom_frame_id: odom
    base_frame_id: base_link
    pose_covariance_diagonal : [0.001, 0.001, 0.001, 0.001, 0.001, 0.01]
    twist_covariance_diagonal: [0.001, 0.001, 0.001, 0.001, 0.001, 0.01]

    open_loop: true
    enable_odom_tf: true

    cmd_vel_timeout: 0.5
    #publish_limited_velocity: true
    use_stamped_vel: false
    #velocity_rolling_window_size: 10

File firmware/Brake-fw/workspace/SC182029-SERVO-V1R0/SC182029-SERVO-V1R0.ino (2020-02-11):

/* ================================================================

   Proyecto: Modulo de encoder en andador para UMA
   Placa de desarrollo: Arduino
   Función: Gira entre 0 y 90 grados la posición del servo empujando
			el cable de freno, tiene un led indicador y envía los datos a
			través del BUS CAN.
			
   Autor: Justo Barroso Fontalba
   Fecha: 19/03/2019

   ================================================================ */

/* ================================================================
   Librerías
   ================================================================ */

#include <SPI.h>
#include <Servo.h>
#include <mcp_can.h>

/* ================================================================
   Definición de pines
   ================================================================ */

//ATMega328 TQFP
//                    Pin IDE //Pin puerto, Pin Físico
#define LED_GATE        7     //PD7, 11
#define MCP2515_STBY    8     //PB0, 12
#define MCP2515_CS      4     //PD4, 2
#define MCP2515_INT     3     //PD3, 1
#define SERVO           16    //PC2, 25
#define SENSE           17    //PC3, 26
#define ID_CHG          14    //PC0, 23
//#define MCP2515_SI      11    //PB3, 15
//#define MCP2515_SO      12    //PB4, 16
//#define MCP2515_SCK     13    //PB5, 17

//Test en Arduino UNO
//#define MCP2515_CS      10
//#define MCP2515_INT     2
//#define SERVO           3       //PD3, 5  (Arduino UNO)

//Constantes
#define ID_RIGHT      0x013   //Identificador del modulo derecho
#define ID_LEFT       0x023   //Identificador del modulo izquierdo
#define MAX_CURRENT   715     //Valor máximo de corriente en el servo 1.75A

/* ================================================================
   Definición de funciones
   ================================================================ */

/* ================================================================
   Definición de estructuras
   ================================================================ */

/* ================================================================
   Definición de variables
   ================================================================ */

static long unsigned int rxId; //Identificador del mensaje
static byte len = 0; //Longitud del mensaje
static byte rxBuf[8]; //Array datos de recepción
static byte txBuf[8] = { 0x00, 0x00, 0x00, 0xDD, 0x00, 0xFF, 0x00, 0x00 }; //Array datos de envió
static byte id_device = ID_LEFT;

/* ================================================================
   Drivers
   ================================================================ */

Servo servoMotor;

/* ================================================================
   Inicialización
   ================================================================ */

MCP_CAN CAN0( MCP2515_CS ); // Establece el CS en el pin 10

void setup() {
  //Configuración de pines
  pinMode( LED_GATE, OUTPUT );
  pinMode( SENSE, INPUT );
  pinMode( MCP2515_INT, INPUT_PULLUP ); // Interrupción MCP2515
  pinMode( MCP2515_STBY, OUTPUT ); // CS MCP2515  
  pinMode( ID_CHG, INPUT_PULLUP ); // Selección izquierda/derecha
  digitalWrite( MCP2515_STBY, LOW ); // Modo normal activo MCP2562

  //Establece la posición del modulo en el andador
  if ( digitalRead( ID_CHG ) == 0 ) {
    id_device = ID_RIGHT;
  }

  //Inicialización de puerto serie
  Serial.begin( 115200 );

  //Inicialización MCP2515, mascara y filtros activados, velocidad 500kb/s, cristal 16MHz
  if ( CAN0.begin( MCP_STDEXT, CAN_500KBPS, MCP_16MHZ ) == CAN_OK ) {
    Serial.println( "MCP2515 Initialized Successfully!" );
  }
  else {
    Serial.println( "Error Initializing MCP2515..." );
  }

  //Establece mascaras y filtros para los dispositivos
  CAN0.init_Mask( 0, 0, 0x001F0000 ); // Iniciando primera mascara
  CAN0.init_Filt( 0, 0, 0x00100000 ); // Iniciando primer filtro, ID 0x10 (rPi)

  CAN0.init_Mask( 1, 0, 0x001F0000 ); // Iniciando segunda mascara

  //Configuración del MCP2515
  CAN0.setMode( MCP_NORMAL ); // Modo normal para permitir el envio de mensajes

  //Configuración de pines
  servoMotor.attach( SERVO );

  //Establecer el angulo a 0
  servoMotor.write( 150 );

  //Configurando la interrupción por pin
  attachInterrupt( digitalPinToInterrupt( MCP2515_INT ), readCAN, LOW );

  for (int i = 0; i < 3; i++)
  {
    digitalWrite( LED_GATE, LOW );
    delay(200);
    digitalWrite( LED_GATE, HIGH );
    delay(200);
  }
}

/* ================================================================
   Bucle principal
   ================================================================ */

void loop() {
  
}

/* ================================================================
   Interrupciones
   ================================================================ */

void readCAN() {
  CAN0.readMsgBuf( &rxId, &len, rxBuf ); // Leer datos: len = longitud de los datos, buf = bytes de datos
  if ( rxBuf[0] == id_device ) {
    if ( ( rxBuf[1] & 0b00000001 ) == 0b00000001 ) {
      //if ( ( PIND & B10000000 ) == B00000000 ) {
        digitalWrite( LED_GATE, LOW ); //Enciende el LED
        Serial.println( "Led encendido" );
      //}
    }
    if ( ( rxBuf[1] & 0b00000001 ) == 0b00000000 ) {
      //if ( ( PIND & B10000000 ) == B00000100 ) {
        digitalWrite( LED_GATE, HIGH ); //Apaga el LED
        Serial.println( "Led apagado" );
      //}
    }
    //Rango operativo del servo entre 70 y 150 o 0x46 (90 grados) y 0x96 (0 grados)
    if ( ( rxBuf[1] & 0b00000010 ) == 0b00000010 ) {
      if ( rxBuf[2] <= 0x96 && rxBuf[2] >= 0x46 ) {
        servoMotor.write( rxBuf[2] ); //valor al servo
        //Serial.println( analogRead( SENSE ) );
        while ( analogRead( SENSE ) >= MAX_CURRENT ) {
          servoMotor.write( rxBuf[2] -= 0x05 );
          Serial.println( "Se ha reducido la fuerza ejercida sobre el freno." );
        }        
      }
      Serial.println( "Valor establecido: " );
      Serial.println( rxBuf[2] );
    }
  }
}

/* ================================================================
   Funciones
   ================================================================ */

/* ================================================================
   Fin
   ================================================================ */

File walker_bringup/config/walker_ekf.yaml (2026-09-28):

walker_ekf_node:
    ros__parameters:
        # 30 Hz prediction lets the filter actually make use of the IMU's
        # ~50-100 Hz angular-velocity stream between the much slower (~5-6 Hz,
        # see /scan in the mocap bags) laser-odometry corrections; the
        # previous 5.0 Hz meant the filter only ever ran as fast as the
        # laser, wasting the IMU's rate advantage.
        frequency: 30.0
        # Longer than the laser's ~0.16-0.18s scan period (5-6 Hz) so odom0
        # isn't flagged as timed out between every pair of scans; the
        # previous 0.1s was shorter than that period.
        sensor_timeout: 0.5
        two_d_mode: true
        transform_time_offset: 0.0
        transform_timeout: 0.0
        print_diagnostics: true
        # Raspberry Pi 5 / SD or eMMC storage: robot_localization's debug
        # mode writes a running log to /tmp/robot_localization_debug.txt on
        # every update, which is needless disk I/O in normal operation. Set
        # to true only while diagnosing fusion issues.
        debug: false
        permit_corrected_publication: false
        publish_acceleration: false
        publish_tf: true
        map_frame: map                   # Defaults to "map" if unspecified
        odom_frame: odom                 # Defaults to "odom" if unspecified
        base_link_frame: base_footprint  # Defaults to "base_link" if unspecified
        world_frame: odom                # Defaults to the value of odom_frame if unspecified

# odom0 comes from the laser scan matcher (ros2_laser_scan_matcher / CSM
# PL-ICP), see walker_lsm.yaml. It is the only absolute position+yaw source
# now that the wheel encoders are broken, so x, y and yaw (NOT roll -- a 2D
# lidar match never produces a roll estimate, the previous [x,y,z /
# roll,pitch,yaw] row below had "roll" set true instead of "yaw", so the EKF
# was fusing a field the scan matcher never fills and silently ignoring the
# one absolute heading correction this sensor can actually give it) are
# fused. vx/vy come from consecutive scan-matched poses; angular velocity is
# left to the IMU (odom0's yaw-rate axis was also mis-published until the
# ros2_laser_scan_matcher fix, see laser_scan_matcher.cpp).
        odom0: /scan_odom
        odom0_config: [true,  true,  false,     # x,     y,      z
                       false, false, true,      # roll,  pitch,  yaw
                       true,  true,  false,     # vx,    vy,     vz,
                       false, false, false,     # vroll, vpitch, vyaw
                       false, false, false]     # ax,    ay,     az
        odom0_queue_size: 5
        odom0_nodelay: false
        odom0_differential: false
        odom0_relative: true
        # Mahalanobis-distance gate, in standard deviations of the INNOVATION
        # (measurement + predicted-state covariance combined) -- 1.0 std dev
        # rejects roughly a third of even perfectly-valid Gaussian-noise
        # updates, and combined with the tight initial_estimate_covariance
        # this used to have (see above) produced a lockout: once the filter
        # drifted past ~1 std of its own overconfident belief, it rejected
        # every subsequent correction that would have fixed it. 5.0 is a
        # much more standard gate (blocks genuine outliers, e.g. a bad ICP
        # match, without fighting normal sensor noise).
        odom0_pose_rejection_threshold: 5.0
        odom0_twist_rejection_threshold: 5.0

# odom1 (viso2 stereo) is not part of the lidar+IMU sensor set this config
# targets -- left disabled here (uncomment and provide /visual/odom if a
# stereo camera is added back later; odom0_config/odom1_config layout above
# still applies unchanged).
        # odom1: /visual/odom
        # odom1_config: [true,   true, false,     # x,     y,      z
        #                false, false, true,      # roll,  pitch,  yaw
        #                true,   true, false,     # vx,    vy,     vz,
        #                false, false, false,     # vroll, vpitch, vyaw
        #                false, false, false]     # ax,    ay,     az
        # odom1_queue_size: 2
        # odom1_nodelay: false
        # odom1_differential: true
        # odom1_relative: false
        # odom1_pose_rejection_threshold: 1.0
        # odom1_twist_rejection_threshold: 0.1
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

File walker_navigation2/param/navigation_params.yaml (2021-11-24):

amcl:
  ros__parameters:
    use_sim_time: False
    alpha1: 0.2
    alpha2: 0.2
    alpha3: 0.2
    alpha4: 0.2
    alpha5: 0.2
    base_frame_id: "base_footprint"
    beam_skip_distance: 0.5
    beam_skip_error_threshold: 0.9
    beam_skip_threshold: 0.3
    do_beamskip: false
    global_frame_id: "map"
    lambda_short: 0.1
    laser_likelihood_max_dist: 2.0
    laser_max_range: 100.0
    laser_min_range: -1.0
    laser_model_type: "likelihood_field"
    max_beams: 60
    max_particles: 2000
    min_particles: 500
    odom_frame_id: "odom"
    pf_err: 0.05
    pf_z: 0.99
    recovery_alpha_fast: 0.0
    recovery_alpha_slow: 0.0
    resample_interval: 1
    robot_model_type: "differential"
    save_pose_rate: 0.5
    sigma_hit: 0.2
    tf_broadcast: true
    transform_tolerance: 1.0
    update_min_a: 0.2
    update_min_d: 0.25
    z_hit: 0.5
    z_max: 0.05
    z_rand: 0.5
    z_short: 0.05

amcl_map_client:
  ros__parameters:
    use_sim_time: False

amcl_rclcpp_node:
  ros__parameters:
    use_sim_time: False

bt_navigator:
  ros__parameters:
    use_sim_time: False
    global_frame: map
    robot_base_frame: base_link
    odom_topic: /odom
    default_bt_xml_filename: "navigate_w_replanning_and_recovery.xml"
    plugin_lib_names:
    - nav2_compute_path_to_pose_action_bt_node
    - nav2_follow_path_action_bt_node
    - nav2_back_up_action_bt_node
    - nav2_spin_action_bt_node
    - nav2_wait_action_bt_node
    - nav2_clear_costmap_service_bt_node
    - nav2_is_stuck_condition_bt_node
    - nav2_goal_reached_condition_bt_node
    - nav2_goal_updated_condition_bt_node
    - nav2_initial_pose_received_condition_bt_node
    - nav2_reinitialize_global_localization_service_bt_node
    - nav2_rate_controller_bt_node
    - nav2_distance_controller_bt_node
    - nav2_speed_controller_bt_node
    - nav2_recovery_node_bt_node
    - nav2_pipeline_sequence_bt_node
    - nav2_round_robin_node_bt_node
    - nav2_transform_available_condition_bt_node
    - nav2_time_expired_condition_bt_node
    - nav2_distance_traveled_condition_bt_node

bt_navigator_rclcpp_node:
  ros__parameters:
    use_sim_time: False

controller_server:
  ros__parameters:
    use_sim_time: False
    controller_frequency: 10.0
    min_x_velocity_threshold: 0.001
    min_y_velocity_threshold: 0.5
    min_theta_velocity_threshold: 0.001
    controller_plugins: ["FollowPath"]

    # DWB parameters
    FollowPath:
      plugin: "dwb_core::DWBLocalPlanner"
      debug_trajectory_details: True
      min_vel_x: 0.0
      min_vel_y: 0.0
      max_vel_x: 0.22
      max_vel_y: 0.0
      max_vel_theta: 1.0
      min_speed_xy: 0.0
      max_speed_xy: 0.22
      min_speed_theta: 0.0
      # Add high threshold velocity for turtlebot 3 issue.
      # https://github.com/ROBOTIS-GIT/turtlebot3_simulations/issues/75
      acc_lim_x: 2.5
      acc_lim_y: 0.0
      acc_lim_theta: 3.2
      decel_lim_x: -2.5
      decel_lim_y: 0.0
      decel_lim_theta: -3.2
      vx_samples: 20
      vy_samples: 0
      vtheta_samples: 40
      sim_time: 1.5
      linear_granularity: 0.05
      angular_granularity: 0.025
      transform_tolerance: 0.2
      xy_goal_tolerance: 0.05
      trans_stopped_velocity: 0.25
      short_circuit_trajectory_evaluation: True
      stateful: True
      critics: ["RotateToGoal", "Oscillation", "BaseObstacle", "GoalAlign", "PathAlign", "PathDist", "GoalDist"]
      BaseObstacle.scale: 0.02
      PathAlign.scale: 32.0
      PathAlign.forward_point_distance: 0.1
      GoalAlign.scale: 24.0
      GoalAlign.forward_point_distance: 0.1
      PathDist.scale: 32.0
      GoalDist.scale: 24.0
      RotateToGoal.scale: 32.0
      RotateToGoal.slowing_factor: 5.0
      RotateToGoal.lookahead_time: -1.0

controller_server_rclcpp_node:
  ros__parameters:
    use_sim_time: False
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

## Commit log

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2021-12-10 diff_odom: working version bringup: - tmule script also records data now - lasers are filtered for self collisions
    [walker_odom.cpp]
2021-12-14 - Added config for laser filtering out leg detections - Added tmule file tags to avoid default recording - Added mapper config
    [mapper_params_online_async.yaml]
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2022-01-12 Odometry hardware was in wrong place
    [Boceto.dwg, Boceto_recover.dwg, Dibujo.dwg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]
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2022-02-08 Added vanilla odometry error
    [walker_odom.cpp]
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2022-07-04 Fixing install deps. Adding vars to gui. Publishing config data periodically
    [walker_odom.cpp]
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2023-04-18 WIP: - user stabilitiy node. - renamed topics in stability gridmap - added tinetti into web_gui (and queues set to 0 for performance) - corrected error in walker_loads
    [Correlationes.xlsx]
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2026-09-27 Fix stale/unsafe partial_loads state and rework the diff Kalman tracker
    walker_loads/partial_loads:
    - Clamp leg_load_ and SplineFunction::interp() to physically valid ranges
    instead of letting out-of-range handle readings extrapolate unbounded.
    - Validate user_desc weight, gate freshness of every input stream with a
    timeout (data_timeout_s), and dispatch left/right handle callbacks by
    topic instead of by matching a substring in frame_id.
    - Subscribe to /user_desc (now a walker_msgs/UserDesc, not a ':'-separated
    String) with transient_local QoS so a (re)started node still picks up a
    profile the GUI already published, matching every other subscriber.
    - Replace the hard 50/50->100/0 t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
2026-09-27 Rework walker_centroid_support and adopt walker_msgs/UserDesc
    walker_centroid_support:
    - Fix missing 'import sys' that turned a real crash into a NameError,
    masking the original exception.
    - Normalize the centroid by the sum of the four measured contact loads
    instead of the user's declared weight (/user_desc): they only match
    exactly when partial_loads hasn't had to clamp leg_load to absorb
    handle-calibration/sensor noise. Normalizing by what was actually
    measured keeps this a true barycenter (weights sum to 1) in both
    cases. As a result the node no longer needs /user_desc at all.
    - Re-resolve the handle-to-step TF every cycle instead of caching it
    once, so a runtime handle_hei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
2026-09-28 Replace broken wheel-encoder odometry with laser-inertial (lidar+IMU) EKF
    walker_diff_odom depends on wheel encoders that are now dead hardware
    (confirmed: /right_wheel has 0 messages in bagsFolder_unified/CA_test01).
    Adds a laser scan matching (ros2_laser_scan_matcher/CSM) + WitMotion IMU
    fusion pipeline via robot_localization as a drop-in replacement, built
    entirely from existing bringup pieces (laser filter chain, walker_lsm,
    walker_witmotion) that just weren't wired together for this purpose yet.
    - walker_ekf.yaml: fix odom0_config (was fusing "roll", which a 2D lidar
    never produces, instead of "yaw" - the EKF was silently discarding the
    only absolute heading correction this sensor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
    [walker_ekf.yaml, walker_lsm.yaml]
2026-09-29 Improve step-detector reliability and validate against mocap ground truth
    detect_steps (RF) match_rate against 47 mocap-labeled bags
    (soma13kp/datasets/labeled_bags) went from ~55-64% to ~95.7-95.9%, swap
    rate down to ~9.3 per 100 consecutive pairs, mean position error ~10cm.
    docs/detect_steps_algorithm.md has the full algorithm description and
    the numbered history of every fix and every rejected attempt, each with
    its 47-bag before/after numbers (eval_results/ has the raw JSON for each
    run). Highlights:
    Landed:
    - Dead confidence-filter/cluster-cap bug in detect_steps.cpp (the single
    biggest win).
    - Track continuity: distance gating, exclusive left/right pairing, lost
    track recovery, on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
2026-10-01 Add km_detect_steps confidence filter and fix critical EKF t=0 init bug
    km_detect_steps.cpp::getCentroids() forced exactly 2 k-means clusters onto
    every candidate publish with confidence always 1, no quality filter --
    unlike detect_steps (RF), which already discards clusters with too few
    points. find_centroid() now also returns used_points (previously computed
    and discarded); getCentroids() skips publishing a cluster below
    min_points_per_cluster (new param, default 3, same name/value as RF). Can
    now emit 0/1/2 candidates per frame depending on quality instead of
    always 2 -- LegsTracker already handled that.
    That filter turned out not to be the cause of the specific bug it was
    meant to fix: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
2026-10-08 walker_laser_imu_odom: launch only laser odometry and the EKF
    The launcher is meant to run alongside the real robot, which already starts
    the IMU driver/filter (walker_witmotion) and the laser filter chain
    (laser_filter -> nav_laser_filter -> /scan_nav). It no longer includes any of
    them: it starts ros2_laser_scan_matcher (consuming /scan_nav) and
    robot_localization's ekf_node, and expects /scan_nav, /bwt901cl/imu_filtered
    and the walker TF from outside.
    Adds lsm_params_file and ekf_params_file arguments (defaulting to the
    production configs) so parameters can be tuned from a test launcher without
    editing them.
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2026-10-08 walker_mocap_eval: mocap-vs-walker validation report pipeline and new metrics
    Add the full report pipeline (compute_*, export_bag_timeseries,
    derive_comparison_metrics, build_master_report_data, generate_latex_report)
    with per-subject aggregation, CoG (De Leva), extra posture metrics, and
    the extension with IMU stability (RMS/Harmonic Ratio/autocorrelation),
    handle-force Symmetry Index and lean-vs-margin correlation, plus selftests
    and scripts/README.md with the execution order.
    Comparison against the replayed walker is restricted to rows inside the
    /tag window and reports median error (MedAPE) next to MAPE. The report
    states that d/WV do not validate the walker's odometry, since /odom in
    t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
2026-10-08 walker_loads/walker_msgs: bag-time stamps for gait stats and offline replay setup
    WalkStats gets a std_msgs/Header, and gait_monitor_speed stamps it (the
    GaitStamped ones were already stamped). With use_sim_time and
    `ros2 bag play --clock` in replay_offline.launch.py these stamps are bag
    time instead of wall time, so replayed gait stats can be aligned with
    mocap series.
    replay_offline.launch.py: start_offset (crop to the /tag window), swap to
    the RF detect_steps with the validated parameters, laser box filter,
    walker_centroid_support, and the mocap-derived /odom bridge (the wheel
    encoders in these bags are unusable).
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2026-10-11 Reorganize walker_bringup: cleanup, launch/test, udev docs, README
    - Remove unused configs/launchers/params and turtlebot3 leftovers
    - Rename walker_efk.launch.py to walker_ekf.launch.py
    - Move launchers not used by any tmule session to launch/test
    - Move find_minimums/laser_filter_generator to walker_laser_filter
    - Document udev rules for /dev/rplidar and /dev/witmotion
    - Empty maps/ (placeholder), add README, fix package.xml dependencies
2026-10-11 walker_description: witmotion is mounted z-up (roll 0, not 180)
    The IMU's static accelerometer reads +9.8 m/s2 on its z axis and its gyro z
    correlates +0.99 with the mocap yaw rate in bags of every session, so the sensor
    z points up. The xacro declared roll=180 deg, which made robot_localization flip
    the sign of the fused yaw rate: the IMU made the odometry heading worse (3.81 deg
    RMS against 2.50 deg for the laser alone) instead of better.
2026-10-11 Tune laser-inertial odometry: raw gyro, realistic covariances, scan time offset
    Tuned against mocap ground truth on 47 bags (32 clean ones for the score, 3
    repetitions per candidate; evaluation noise sigma ~0.007-0.01).
    - walker_ekf.yaml: fuse /bwt901cl/imu (raw), not imu_filtered. The complementary
    filter's bias estimator assumes a stationary sensor and, while moving, subtracts
    an invented bias of up to 7 deg/s, different in every bag; the raw gyro z has
    offset 0.000 +-0.003 rad/s, scale 1.00 and correlation 0.99-1.00. Only vyaw is
    fused. Process noise of yaw 0.06 -> 0.001.
    - walker_lsm.yaml: yaw covariance 0.0012 -> 0.05 (successive scan matches are
    chained to one keyframe, so t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
2026-10-11 Launchers: consume the raw IMU and stop DEBUG logging leaking into replays
    walker_laser_imu_odom documents that it expects /bwt901cl/imu (raw), not the
    filtered topic.
    unified_bag_replay includes walker_state_publisher.launch.py, which declares
    log_level=DEBUG by default; launch arguments of an included description leak
    into the parent scope, so every launch included afterwards (scan matcher, EKF)
    inherited --log-level DEBUG and drowned the machine in logs, which truncated
    replays when several ran in parallel. It now passes log_level=warn and
    use_sim_time=true explicitly.
2026-10-11 walker_bringup: single odometry launcher, drop the dead encoder odometry
    - Remove walker_ekf.launch.py: walker_laser_imu_odom.launch.py replaces it (same
    robot_localization node, now fusing the raw gyro with the tuned covariances). Its
    only consumer, walker_rtabmap.launch.py, now takes /odom instead of /ekf_odom.
    - walker_leap.yaml: stop launching walker_diff_odom; the wheel encoders it reads
    are broken hardware.
    - walker_controllers.yaml and the legacy test/robot.launch.py default to
    base_footprint (the odometry child frame everywhere else).
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2026-10-11 walker_mocap_eval: add the laser-inertial odometry tuning toolkit
    scripts/odom_tuning/ records the scan matcher once per bag (stage1), replays only the
    EKF over it (harness) and scores against the mocap with the same functions as
    eval_odom_against_mocap.py, separating heading error into constant bias and drift.
    harness.prod_cfg() is built from the committed walker_bringup configs, so it always
    tests what is in the repo. Includes diagnose_bags.py (arbitrates laser vs mocap errors
    with the raw gyro), gyro_check.py (IMU sign/scale/bias/clock against mocap) and
    compare.py (repeated runs with mean and std) because a single measurement of a
    candidate proved to be luck of selection, not a result.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
2026-10-11 Enable the gyro ICP prior and re-tune the heading weights around it
    walker_lsm.yaml: imu_topic /bwt901cl/imu (raw gyro) turns the prior on, with the
    arbitration against the unseeded ICP (ratio 0.7) that makes a wrong-sign or faulty
    gyro harmless. The laser heading variance goes from 0.05 to 0.2 rad2: successive
    scan matches are chained to one keyframe, so they are not independent heading
    measurements, and with the gyro seeding the ICP the heading is dominated by the gyro
    and the laser only anchors it slowly.
    walker_ekf.yaml: process noise of yaw 0.001 -> 0.0003 to match.
    Measured against mocap on 32 clean bags (3 repetitions per candidate): /odom heading
    2.16 -> 1.91 deg, ATE 0.208 -> 0.20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
2026-10-11 odom_tuning: --lsm-set for stage1, note on the prior in bag_quality
    stage1.py takes --lsm-set key=value (repeatable, YAML-parsed) to fix scan matcher
    parameters when recording, so a change such as the gyro prior can be recorded into a
    separate ODOM_TUNE_DIR and compared against the previous recording.
    bag_quality.yaml notes that the anomalous labels describe the scan matcher WITHOUT the
    gyro prior; with it those bags drop from 13.9 to 5.9 deg on average but stay set aside
    so the clean score does not mix regimes.
2026-10-11 walker_mocap_eval readme: gyro ICP prior implemented, results and two lessons
    Replaces the pending "next step": the prior is implemented and enabled, with the figures
    against mocap, how to re-record with and without it, and two lessons that are expensive
    to rediscover: checking the seeded ICP against the gyro does not detect a wrong gyro
    (the arbitration against the unseeded ICP does), and the best candidate of a search with
    a single measurement is usually luck. Also records that a lost gyro now roughly doubles
    the heading error of the EKF.
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2026-10-12 walker_mocap_eval: gait/stability metrics read the raw /bwt901cl/imu
    Only linear_acceleration is used and imu_complementary_filter passed it through
    unchanged, so the numbers do not change. /bwt901cl/imu_filtered stays as a
    fallback for old bags; new recordings will not carry it any more.
2026-10-12 walker_bringup: odom_supervisor switches EKF covariances when the gyro fails
    The EKF is built around the gyro (the laser heading variance is deliberately
    loose), and robot_localization cannot switch covariances by itself. The new
    node sits between /scan_odom + /bwt901cl/imu and the EKF (/scan_odom_ekf,
    /imu_ekf) and, on intrinsic gyro failures only (no messages, out of range,
    sign/dead gyro during a turn, bias on straights), makes the laser heading
    strong and the gyro variance huge. Sign/bias failures are latched until
    positive evidence clears them. Laser-vs-gyro disagreement alone never
    switches: in the anomalous bags the gyro is right and the laser wrong.
    With the supervisor the odom0 Mah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
2026-10-12 odom_tuning: mocap clock-warp correction and bag reclassification
    The six 'mocap_suspect' bags were mocap clock offset/drift against the robot
    clock, not a bad rigid body: time_warp.yaml (fitted by maximising gyro-mocap
    yaw-rate correlation) brings laser and mocap total rotation within 1.5 %.
    MT_test15 becomes clean (33 bags); CA_test05/06 and MT_test12-14 move to a new
    imu_gyro_scale group because their gyro integral is 5-7 % off the laser, which
    makes the production EKF worse than the scan matcher alone there. New
    --bags imu_anom selector.
2026-10-12 odom_tuning: fault-injection test for odom_supervisor
    harness.py can interpose the supervisor between the replay and the EKF;
    tune_node.py injects IMU dropouts; supervisor_test.py runs normal / IMU
    dropout / inverted sign / bias scenarios with and without the supervisor and
    counts spurious switches (options --rej, --sup, --set, --scenarios).
2026-10-12 odom_supervisor: tuned detection defaults (20 deg / 4 s / 1 s)
    Swept turn_min_deg / window_s / persist_s with fault injection on 12 clean
    bags plus false-trigger counts on 33 clean, 8 scan-matching-anomalous and 5
    imu_gyro_scale bags. 20/4/1 detects an inverted gyro within the first turn
    (heading 67 -> 6.4 deg, was 28 with 45/8/2) and a +0.05 rad/s bias
    (6.3 -> 2.7 deg), with 1/33 spurious switches on clean bags (a replay startup
    race) and 0/8 on the anomalous ones.
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2026-10-12 odom_tuning: fit_time_warp.py reproduces the mocap time-axis correction
    Per-bag fit of offset + linear drift that maximises the correlation between
    the mocap yaw rate and the raw gyro (windowed lag, robust line, refinement of
    the global correlation). It reproduces the committed time_warp.yaml to
    <= 0.2 s over the bag; MT_test18 sits just under the 0.01 gain threshold.
    The yaml header cited a fit_time_warp.py that did not exist.
2026-10-12 odom_tuning: describe the mocap time warp as an empirical mismatch
    Header stamps of the mocap, IMU and scan all agree with the recording time and
    the mocap frame_number runs at 120.000 fps, so the data do not support
    'unsynchronised PC clocks'. Reword time_warp.yaml, bag_quality.yaml and
    gyro_check.py accordingly: cause unidentified, sign of the drift matches the
    gyro/laser scale ratio in the five large-drift bags, small constant offsets
    look like mocap latency. Values are unchanged.
2026-10-12 eval_odom_against_mocap: apply the mocap time-axis correction of time_warp.yaml
    The evaluator used the raw mocap time axis, so the bags whose mocap is
    shifted/scaled against the robot sensors (up to 5 s and 7 %) scored as bad
    odometry. It now looks the bag up in odom_tuning/time_warp.yaml (key deduced
    from the eval-bag directory name, or --bag-name), pairs by header stamps
    (--time-basis header, the default; record keeps the old behaviour without the
    correction) and reports what it applied; --time-warp none disables it.
    load_time_warp/warp_ns/find_warp live here and tlib.py reuses them.
    On a synthetic eval bag of CA_test05: ATE rmse 0.523 -> 0.113 m, heading rmse
    16.2 -> 3.07 deg, matching t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
2026-10-14 walker_bringup: walker_laser_imu_odom_test replays through walker_replay
    The odometry test bench no longer includes unified_bag_replay.launch.py: it
    adds walker_replay.replay_actions() before its nodes, which plays the
    definitive bag with /clock, propagates use_sim_time and publishes the walker
    tf (URDF + handles), /user_desc and /handle_height.
    Arguments: bag_path is replaced by bag_folder/bag_name; sim_time (true here,
    it is a bag test bench) and debug are exposed.
2026-10-14 walker_step_detector: test launchers and multibag eval replay through walker_replay
    test_step_detector.launch.py and test_step_detector_variants.launch.py no
    longer include unified_bag_replay or run their own `ros2 bag play`: they use
    walker_replay.replay_actions() before their nodes (clock, use_sim_time for
    the whole test, URDF tf).
    Arguments: bag_path is replaced by bag_folder/bag_name (definitive bags),
    replay_delay by delay, publish_walker_tf is gone (walker_replay publish_tf);
    sim_time (true) and debug are exposed. /tf and /tf_static are no longer
    replayed. run_multibag_eval.py passes bag_folder/bag_name/delay and does not
    repair the bag metadata any more (definitive bags are well form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
2026-10-15 walker_loads: replay_offline gets /odom from the mocap_odometry node
    Replaces the mocap_odom_bridge.py script of walker_mocap_eval (removed) with
    the mocap_odometry node: rigid body 0 calibrated to base_footprint, with
    twist. walker_loads depends on mocap_odometry.
2026-10-15 walker_mocap_eval: mocap odometry code lives in mocap_odometry
    mocap_to_base_footprint, warp_ns, find_warp, wrap_angle and yaw_from_quat of
    eval_odom_against_mocap.py are now aliases of mocap_odometry.core; the
    mocap_odom_bridge.py node is removed (mocap_odometry replaces it). Docs
    updated. The calibration and time_warp yaml files stay where they are.
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2026-10-16 Odometry tuning and evaluation tools moved to mocap_odometry
    walker_mocap_eval/scripts/odom_tuning and eval_odom_against_mocap.py now live
    in mocap4w/mocap_odometry, and walker_bringup's walker_laser_imu_odom_test
    launcher is removed (compare_odometry.launch.py replaces it). Docs and config
    comments point to the new location.
2026-10-16 walker_loads: partial_loads works on data time
    No timer and no clock: the four stamped inputs go through a StampSequencer
    and the leg loads are sampled and published on a fixed grid of data time
    (ms_period, now 50 by default). The Kalman tracker steps by the difference
    of the stamps and the first measurement starts its clock. Same inputs give
    the same outputs bit for bit, at any replay rate. New parameter max_wait_s;
    publishers and subscriptions get deep queues because the output is bursty.
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2026-10-16 walker_laser_filter: box_filter and mask_filter no longer drop scans that arrive in bursts
    Both polled with spin_some() every 5 ms (WallRate 200) on a subscription
    with the system-default QoS (best effort, tiny history), so when scans came
    a few ms apart (CA_test01 has 8 such pairs/triplets in 500 scans) the first
    was overwritten by the next one before the loop looked: 8-11 of 500 scans
    lost per replay, which made the whole chain non-repeatable. Now rclcpp::spin()
    and sensor-data QoS (still best effort, so it matches the same publishers)
    with a 100-deep history: 500/500 in all runs.
2026-10-16 walker_step_detector: detect_steps and km_detect_steps keep scans that arrive in bursts
    Same cause as the laser filters: the scan subscription used the system-default
    QoS (best effort, tiny history), so a third scan arriving while one was being
    processed and another was waiting overwrote it. Sensor-data QoS with a
    100-deep history; with the laser filter fix, the whole chain from raw /scan
    (loads, centroid and gait summaries included) is bit-identical between runs.
2026-10-18 python nodes: a stop by signal is a normal stop, not a traceback
    rclpy.spin() raises ExternalShutdownException when the context is shut down
    by SIGINT/SIGTERM (what ros2 launch sends on shutdown), and then
    rclpy.shutdown() fails with 'rcl_shutdown already called'. Result: every
    python node of the workspace ended with two tracebacks and 'process has died,
    exit code 1'. Both are now handled (ExternalShutdownException is a normal
    stop; shutdown only if the context is still valid): the nodes finish cleanly.
2026-10-18 walker_loads: the Kalman filter starts with the gait phase unknown (kalman_theta_sigma = pi)
    The data-time change made the filter's first step 0 instead of the absolute clock (~1.7e9 s). That huge step had been
    inflating the covariance of the phase to ~1e19 as a side effect, i.e. the phase was free and the first measurements
    set it; with the P0 of 1 rad the filter trusted its 0.20 rad prior and locked on a wrong phase. I measured the
    data-time version only on step counts and gait parameters, and missed it: on MF_test07 the right-leg load fraction
    averaged 0.73 and the dominant leg agreed with the mocap 59 % of the time (mocap_loads compare_loads).
    The initial phase uncertainty is now a para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
2026-10-18 walker_diff_odom: the wheel odometry works on data time
    The wheel odometry sampled the encoder counts on a wall timer and took the stamps and the velocities from the clock:
    at replay rate 4 it published a quarter of the messages per second of data, the velocities depended on timer
    jitter, and two updates in the same simulated-clock tick divided by zero (nan velocities at rate 1). The two
    encoder streams go through a StampSequencer now and the odometry is published on a fixed grid of data time
    (tf_rate_hz) with the state as of each tick, stamped with the tick. Parameter max_wait_s (1 s) bounds the wait for a
    silent wheel; the encoder subscriptions get a deep best-effort history.
    Checked on L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
2026-10-18 walker_step_detector: detect_steps_fused works on data time; detect_steps_s keeps segments that arrive in bursts
    detect_steps_fused stamped its caches and ran its tracker with this->now() (the same bug already fixed in detect_steps
    and km_detect_steps) and used the latest km/seg array received when the RF one arrived, which depends on topic order.
    The three sources go through a StampSequencer now (km and seg of a scan are in before its RF array), the freshness
    window and the tracker time are the scan's stamp. Checked on MF_test07 with test_step_detector_variants: the fused
    outputs are bit-identical in 2 runs at rate 4 and 1 at rate 1 (378 steps per side).
    detect_steps_s: scan-style QoS with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
2026-10-18 walker_stability: the node runs, and its index is what it was documented to be
    The node did not run (no shebang, tf2_geometry_msgs not imported so every transform failed, the launch file started
    partial_loads, pandas needed an openpyxl newer than installed) and the model had four defects: degrees fed to sin/cos,
    UserDesc.height in cm used as metres, two linear ramps instead of 'maximum in the centre', and an age lookup that used
    the first bracket for any younger user. The base of support is now a tested pure-python module (bos.py, vectorised,
    cached per user and handle height, no pandas), the executable is user_stability.py (walker_stability.py shadowed its
    own package), the launch file gets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

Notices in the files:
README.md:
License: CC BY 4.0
